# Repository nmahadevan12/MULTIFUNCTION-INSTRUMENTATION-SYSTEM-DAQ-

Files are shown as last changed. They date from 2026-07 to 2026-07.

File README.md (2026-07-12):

# Multifunction Instrumentation System (M.I.S.)

**Developed by Nikhil Mahadevan**

A portable, Raspberry Pi–powered electronic test bench that replaces six lab instruments — ohmmeter, voltmeter, DC reference, square/sine function generator, and frequency meter — with one integrated DAQ platform.




[]()
[]()

---

## Table of Contents

- [Overview](#overview)
- [Instrument Summary](#instrument-summary)
- [System Architecture](#system-architecture)
- [Software Architecture](#software-architecture)
- [Hardware Design](#hardware-design)
  - [Power Supply](#41--12-v-power-supply)
  - [Ohmmeter](#42-ohmmeter)
  - [Voltmeter](#43-voltmeter)
  - [DC Reference](#44-dc-reference)
  - [Square Wave Generator](#45-square-wave-generator)
  - [Sine Wave Measurement](#46-sine-wave-measurement-frequency-meter)
  - [Sine Wave Generator](#47-sine-wave-generator)
- [PCB Design](#pcb-design-kicad)
- [GPIO Pin Map](#gpio-pin-map-system)
- [Getting Started](#getting-started)
- [Demo Videos](#demo-videos)
- [Skills Demonstrated](#skills-demonstrated)

---

## Overview

The Multifunction Instrumentation System integrates oscilloscopes, function generators, and multimeters into a single-board computer platform using the **Raspberry Pi 4** as the central processing unit. Custom analog front-end circuits handle signal conditioning, comparison, and generation; Python firmware orchestrates measurement, waveform output, and a responsive menu-driven UI from a single application.

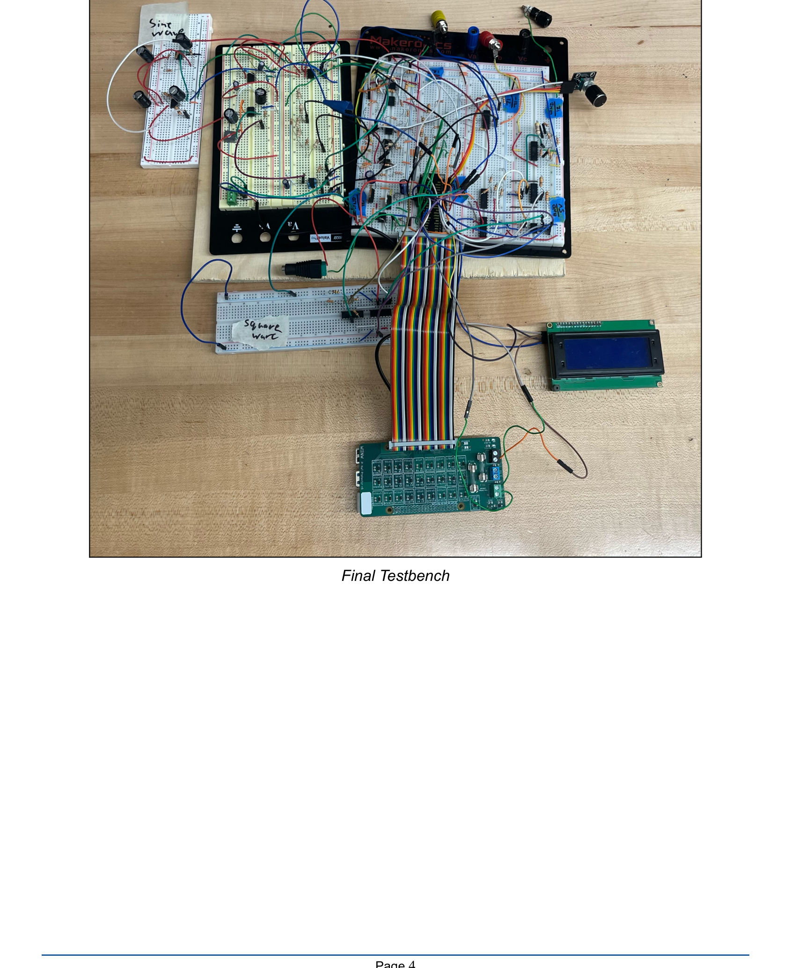
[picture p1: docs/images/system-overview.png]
Final test bench assembly


> [!TIP]
> **Documentation convention:** Images show only schematics, photos, and oscilloscope captures. All objectives, theory, and figure captions are written as markdown text below each image.

<details open>
<summary><strong>At a Glance</strong></summary>

| | |
|---|---|
| **Controller** | Raspberry Pi 4 (sole processor — no external MCU) |
| **Interface** | 20×4 I²C LCD + KY-040 rotary encoder with pushbutton |
| **Analog front-end** | TL084/TL081 op-amps, LM339 comparators, MCP4131/MCP4231 digipots |
| **Power** | 24 V DC input → ±12 V virtual-ground split-rail supply |
| **Firmware** | ~970 lines of Python — SAR measurement, hardware PWM, pigpio edge detection |
| **PCB** | 4-layer KiCad hierarchical design with Gerber manufacturing files |

</details>

<details>
<summary><strong>Project Objectives</strong></summary>

1. **Instrument design**
   - Ohmmeter (500 Ω – 10 kΩ)
   - Voltmeter (−5 V to +5 V)
   - DC reference (−5 V to +5 V)
   - Sine wave frequency measurement (1 – 10 kHz)
   - Function generator — square wave (100 Hz – 10 kHz, ±10 V) and sine wave (1 – 10 kHz, 0 – 10 V pk)

2. **System integration**
   - ±12 V power supply from 24 V input
   - Software-driven successive-approximation measurement (digipot + comparator)
   - Rotary-encoder UI on 20×4 LCD

3. **PCB layout**
   - Full KiCad schematic and 4-layer board design sized to the Raspberry Pi footprint

</details>

<details>
<summary><strong>Design Constraints</strong></summary>

| Category | Constraint |
|---|---|
| **Software** | All logic in Python; pigpio daemon for timing-critical PWM and edge detection |
| **Controller** | Raspberry Pi 4 only — no external microcontrollers |
| **Digipots** | Maximum of 4 digital potentiometers (MCP4131 ×3, MCP4231 ×1 dual-channel) |
| **Power** | All analog power derived from 24 V DC (LCD powered separately); Pi via USB-C |
| **Mechanical** | Pi Hat required — all GPIO routed through hat connector |

</details>

---

## Instrument Summary

| Instrument | Range | Accuracy | Update Rate |
|:---|:---|:---|:---|
| 🔵 **Ohmmeter** | 500 Ω – 10 kΩ | ±10% | 500 ms |
| 🟢 **Voltmeter** | −5 V to +5 V | ±0.2 V | 500 ms |
| 🟡 **DC Reference** | −5.00 V to +4.80 V (32 steps) | ±0.2 V | On demand |
| 🟠 **Square Wave** | 100 Hz – 10 kHz, ±10 V pk | ±1 V amplitude | Real-time PWM |
| 🟣 **Sine Wave** | 1 – 10 kHz, 0 – 10 V pk | ±0.2 V amplitude | Real-time audio |
| 🔴 **Frequency Meter** | 1 – 10 kHz | ±1% | 500 ms |

---

## System Architecture

```mermaid
flowchart LR
    subgraph UI["🖥️ User Interface"]
        LCD["20×4 I²C LCD"]
        ENC["Rotary Encoder"]
    end

    subgraph SW["🐍 Python Firmware"]
        MENU["Menu State Machine"]
        SAR["SAR Engine"]
        PWM["Hardware PWM"]
        FREQ["Edge Detection"]
    end

    subgraph HW["⚡ Analog Front-End"]
        PS["±12V Supply"]
        MEAS["Ohm / Volt"]
        GEN["Wave Gen"]
        DCREF["DC Ref"]
    end

    ENC --> MENU --> LCD
    MENU --> SAR & PWM & FREQ
    SAR & PWM & FREQ --> HW
    PS --> HW
```

---

## Software Architecture

Software is the core of the system — it links the user interface to hardware modules, converts raw comparator signals into resistance/voltage values, controls waveform timing, and keeps the LCD updated.

<details open>
<summary><strong>Platform & Libraries</strong></summary>

| Layer | Technology |
|---|---|
| OS | Raspberry Pi OS |
| Execution | Standalone Python script (`Main Code/16.py`) |
| GPIO / PWM | `RPi.GPIO`, `pigpio` (hardware PWM + µs edge timestamps) |
| SPI | `spidev` — MCP4131 / MCP4231 digital potentiometers |
| I²C | `smbus2`, `RPLCD` — 20×4 character LCD |
| UI input | `gpiozero` — rotary encoder + button callbacks |

</details>

<details>
<summary><strong>Navigation & Main Loop</strong></summary>

The interface is a **stack-based menu tree** with automatic hardware cleanup on back-navigation. Measurement modes sample every **500 ms**; the LCD refreshes on a 50 ms display flag with thread-safe writes.

To ensure a highly responsive user interface, the **500 ms** hardware measurement routines run asynchronously or utilize non-blocking sleep intervals. This prevents the synchronous 8-bit SPI SAR sweeps from blocking encoder interrupt callbacks or delaying the **50 ms** LCD UI refresh cycle.

```
while True:
    if display_needs_update → render_interface()
    if measurement_mode     → sample hardware every 500 ms
    if leaving_mode         → cleanup GPIO / stop waveforms
    sleep(0.05)
```

</details>

<details>
<summary><strong>Per-Instrument Firmware</strong></summary>

| Instrument | Key Implementation |
|---|---|
| **Square wave** | Hardware PWM GPIO 12 + MCP4231 amplitude/offset over SPI |
| **Sine wave** | Pi audio jack + `speaker-test`; MCP4131 amplitude (CS GPIO 17) |
| **Ohmmeter** | 8-iter SAR on MCP4131; `R = R_known × (step / (128 − step))` |
| **Voltmeter** | SAR on GPIO 6; lookup table + linear interpolation |
| **DC Reference** | 5-bit R-2R on GPIO 14, 15, 18, 23, 24 |
| **Frequency** | pigpio edge callbacks GPIO 25; 100-period buffer, >2σ outlier reject |

</details>

> [!IMPORTANT]
> All waveform and DC outputs **automatically disable** when leaving a menu — a built-in safety interlock.

---

## Hardware Design

### 4.1 ±12 V Power Supply

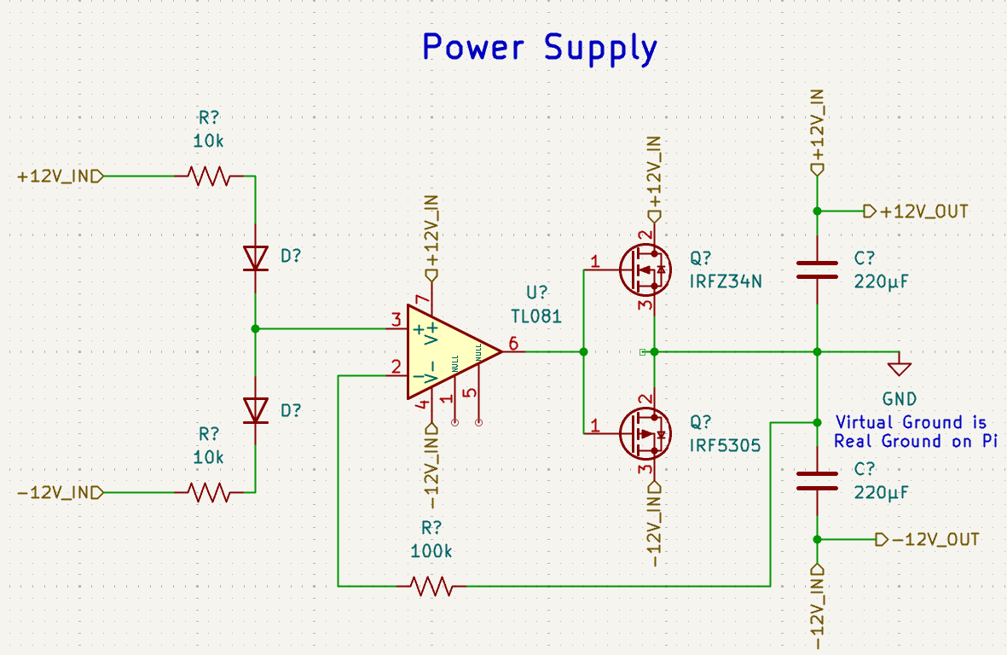
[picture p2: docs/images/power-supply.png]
Power supply schematic


*Figure 4.1.1: Power Supply Schematic*

<details open>
<summary><strong>Power Supply — Theory & Integration</strong></summary>

**Objective:** Split a +24 V DC input into symmetric +12 V and −12 V rails to power op-amps throughout the system. Rails must remain stable under varying load.

**Theory of Operation:** Virtual ground from a 24 V source. TL081 unity-gain follower at the 12 V midpoint drives IRFZ34N + IRF5305 push-pull stage. Virtual ground tied to Pi GND → +12 V above, −12 V below. The virtual ground node acts as the absolute **0 V** reference point for all analog measurements. To prevent heavy analog return currents from injecting noise into the digital plane, the Raspberry Pi GND is tied to this virtual ground at a **single star-ground point** right at the power entry terminal.

1. **Voltage reference:** Matched 10 kΩ divider + Zener clamping → 12 V at TL081 pin 3
2. **Unity-gain buffering:** 100 kΩ feedback drives MOSFET gates
3. **Push-pull output:** NMOS sources / PMOS sinks load current at virtual ground
4. **Output stabilization:** 220 µF bulk caps per rail

**Physical Integration:** Breadboard; ±12 V via terminal blocks. **GPIO:** None — analog only.

</details>

<details>
<summary><strong>Power Supply — Test Results</strong></summary>

| Test Condition | Negative Rail | Positive Rail | Current |
|---|---|---|---|
| Both loads connected | −12.04 V | +12.05 V | ~12 mA each |
| No load | −12.05 V | +12.06 V | — |
| Negative load only | 12.05 V | — | 12.10 mA |
| Positive load only | — | 12.06 V | 12.08 mA |

</details>

> [!WARNING]
> MOSFETs run warm under heavy load. Observe electrolytic capacitor polarity on each rail.

---

### 4.2 Ohmmeter

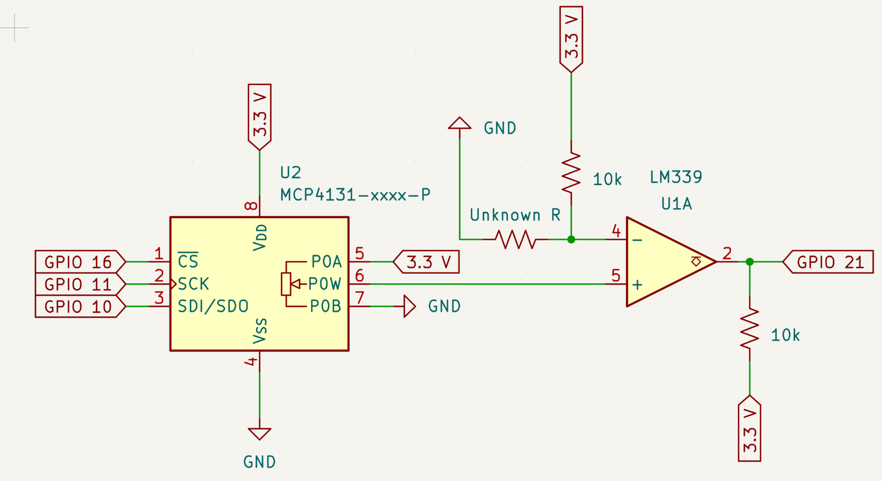
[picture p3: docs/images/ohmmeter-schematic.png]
Ohmmeter schematic


*Figure 4.2.1: Ohmmeter Schematic*

<details open>
<summary><strong>Ohmmeter — Theory & GPIO</strong></summary>

**Objective:** High-accuracy auto-ranging digital ohmmeter for **500 Ω to 10 kΩ**.

**Theory of Operation:** Voltage divider with unknown resistor vs. **7-bit MCP4131** programmable reference. Successive approximation across 128 wiper steps; LM339 comparator on GPIO 21. LCD updates every 500 ms with ±10% tolerance. A fixed series current-limiting resistor (**R_limit = 1 kΩ**) is placed in series with the unknown device under test (DUT). This keeps the maximum current through the MCP4131 wiper well below its absolute maximum rating of **2.5 mA** even when measuring low resistances down to **500 Ω**.

| Signal | GPIO | Component Pin |
|---|---|---|
| Chip Select (CS) | 8 | MCP4131 Pin 1 |
| SPI Clock (SCK) | 11 | MCP4131 Pin 2 |
| SPI Data (SDI/SDO) | 10 | MCP4131 Pin 3 |
| Comparator Output | 21 | LM339 Output |

> [!NOTE]
> **SAR performance (8-bit search):** Each iteration writes one MCP4131 wiper step over SPI (1 MHz, 2-byte frame ≈ 16 µs), waits **5 ms** for the divider/comparator to settle (`sleep(0.005)`), then reads GPIO 21. Eight bisection steps → **≈40 ms** per resistance reading, well under the **500 ms** LCD refresh cadence. Quantization is set by the **128-step** digipot (7-bit effective range); resistance resolution is non-linear with step (`R = R_known × step / (128 − step)`) and tightest near the matched mid-scale point. Because the voltage-divider topology yields a non-linear resolution across the 128-step digipot, measurement precision peaks when the unknown resistance closely matches the internal reference (**R_known**). Near the outer bounds (**500 Ω** and **10 kΩ**), step-size quantization broadens, which accounts for the specified worst-case **±10%** tolerance.

</details>

---

### 4.3 Voltmeter

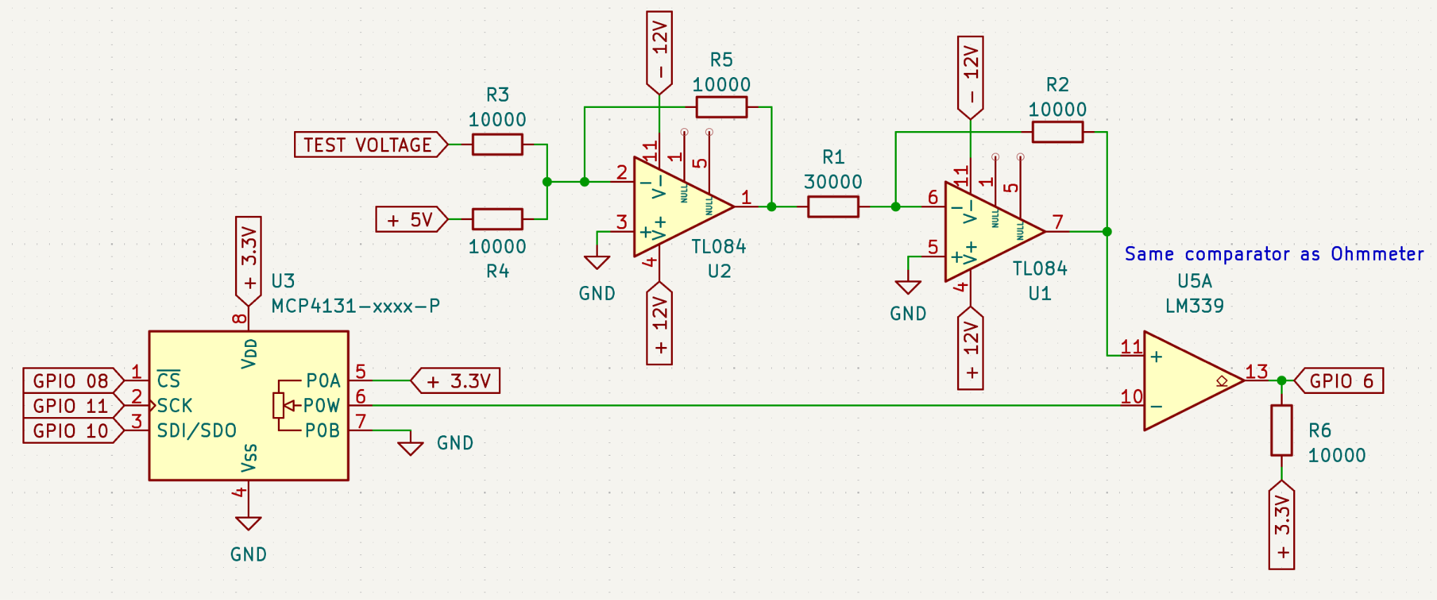
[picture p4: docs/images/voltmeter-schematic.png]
Voltmeter schematic


*Figure 4.3.1: Voltmeter Schematic*

<details open>
<summary><strong>Voltmeter — Theory & GPIO</strong></summary>

**Objective:** Measure **−5 V to +5 V** at ±0.2 V accuracy. Dual-source: external input or internal DC reference verification.

**Theory of Operation:**

1. **U2 — Inverting summing amp:** Maps −5 V to +5 V → 0 V to −10 V
2. **U1 — Inverting amp:** Gain −1/3 → **0 to +3.3 V**
3. **U3 — MCP4131:** 128-step programmable reference via SPI
4. **U5A — LM339:** Comparator with 10 kΩ pull-up
5. **GPIO 6:** Binary search until reference matches test voltage

| Signal | GPIO | Component Pin |
|---|---|---|
| Chip Select (CS) | 8 | MCP4131 Pin 1 |
| SPI Clock (SCK) | 11 | MCP4131 Pin 2 |
| SPI Data (SDI/SDO) | 10 | MCP4131 Pin 3 |
| Comparator Output | 6 | LM339 Pin 13 |

> [!NOTE]
> **SAR performance (8-bit search):** Same 8-iteration binary search as the ohmmeter — one SPI wiper write + **5 ms** settle per step → **≈40 ms** total sweep, safely below the **500 ms** display refresh rate. The ±10 V input span maps to 128 comparator steps, giving a theoretical **≈78 mV/step** (`10 V / 128 ≈ 78 mV`); linear interpolation between calibrated lookup points improves display accuracy to ±0.2 V.

**Calibration & Testing:** Verified against reference multimeter across full range. SAR converges in 8 iterations. ±0.2 V accuracy; best precision near 0 V.

</details>

---

### 4.4 DC Reference

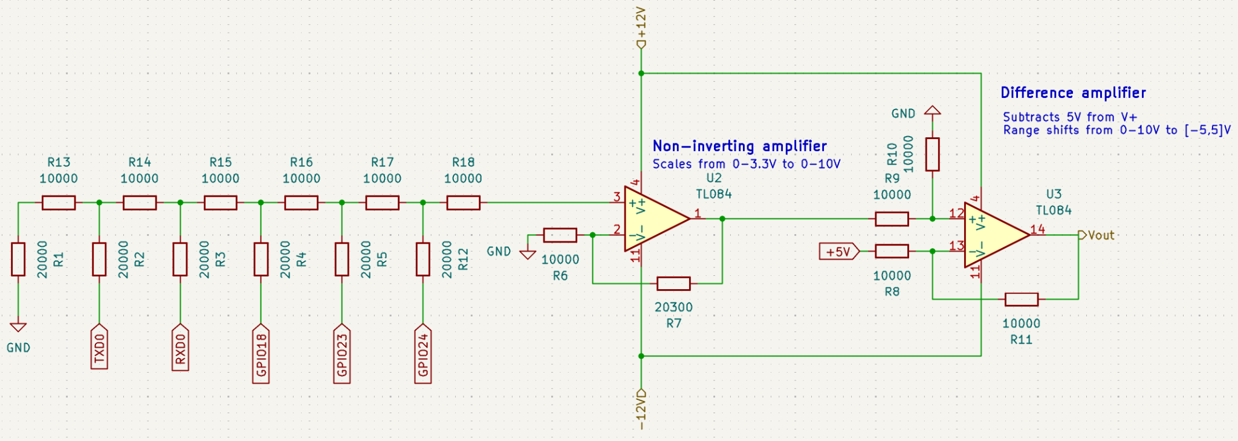
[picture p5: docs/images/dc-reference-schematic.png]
DC reference schematic


*Figure 4.4.1: DC Ref Schematic*

<details open>
<summary><strong>DC Reference — Theory</strong></summary>

**Objective:** Programmable DC output **−5 V to +5 V** in 0.625 V steps (32 levels).

1. **R-2R DAC:** GPIO 14, 15, 18, 23, 24 → binary-weighted divider
2. **U2 — Non-inverting amp:** Gain ≈ 3.03 scales 0–3.3 V → 0–10 V
3. **U3 — Difference amp:** +5 V bias → **−5 V to +5 V** output

**Calibration & Testing:** Output verified across all 32 steps with a reference multimeter. Monotonic response confirmed from −5 V to +5 V.

</details>

<details>
<summary><strong>Previous Design Iteration (Figure 4.4.2)</strong></summary>

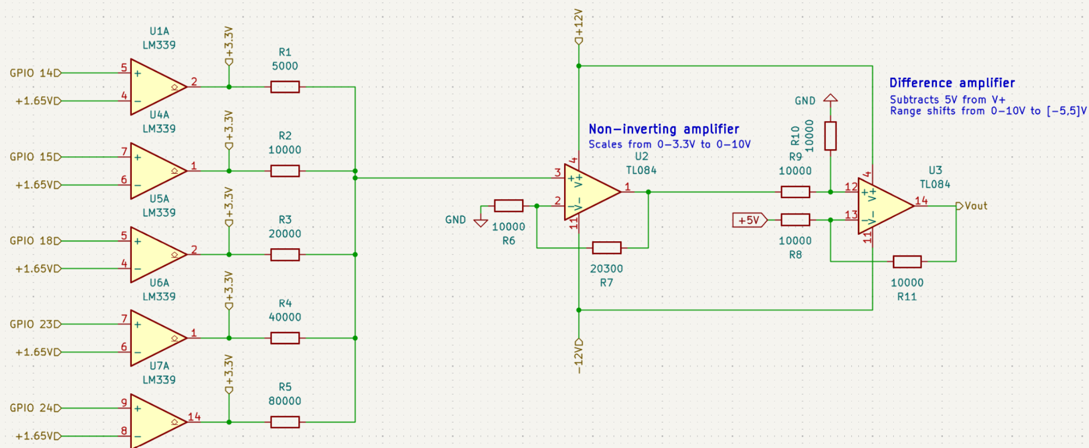
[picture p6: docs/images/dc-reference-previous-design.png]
Previous DC reference schematic


*Figure 4.4.2: Previous DC Ref Schematic*

Original binary-weighted DAC with per-GPIO comparator buffers suffered **cross-loading**. R-2R ladder maintains uniform 2R impedance regardless of bit pattern. The R-2R ladder ensures the digital pins always see a constant output impedance of **R** (or **2R** depending on the node), preventing the voltage sag and non-monotonicity caused by varying pin source impedances in the previous binary-weighted layout.

</details>

---

### 4.5 Square Wave Generator

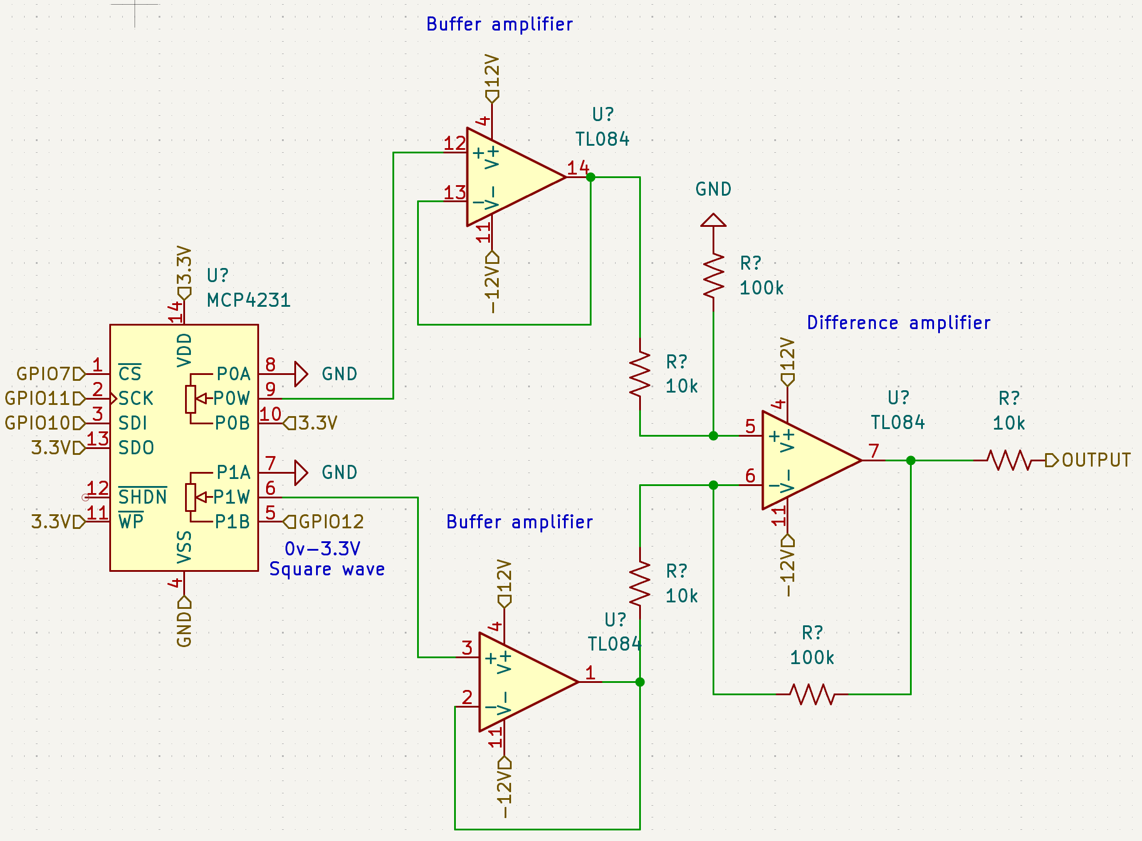
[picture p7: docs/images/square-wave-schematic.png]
Square wave generator schematic


*Figure 4.5.1: Square Wave Schematic*

<details open>
<summary><strong>Square Wave — Theory & GPIO</strong></summary>

**Objective:** Variable square wave centered at **0 V**, up to **±10 V**, high-Z output for oscilloscope use.

**Theory:** Pi hardware PWM GPIO 12 → MCP4231 amplitude + offset → difference amplifier (gain 10) → ±10 V. The hardware PWM output from GPIO 12 passes through a dedicated **RC low-pass filter** stage to smooth high-frequency switching transients and stabilize the signal envelope before amplitude scaling, maintaining waveform integrity across the **100 Hz to 10 kHz** band.

| Signal | GPIO | MCP4231 Pin |
|---|---|---|
| PWM Output | 12 | Ch1 Pin B |
| Chip Select | 7 | Pin 1 |
| SPI Clock | 11 | Pin 3 |
| SPI Data In | 10 | Pin 4 |

**Calibration & Testing:**

- **Figure 4.5.2 — ±7 V initial:** −7.24 V min / +5.95 V max (miscentered)
- **Figure 4.5.3 — ±5 V @ 100 Hz:** Offset ratio **0.45** → ±3% centering
- **Figure 4.5.4 — ±10 V @ 100 Hz:** Full swing confirmed

</details>

<details>
<summary><strong>Oscilloscope Captures</strong></summary>

Oscilloscope — square wave at 1 kHz during initial characterization

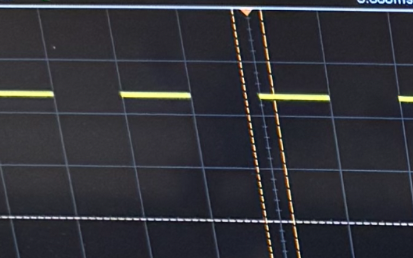
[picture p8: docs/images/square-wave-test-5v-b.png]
Oscilloscope — ±5 V square wave at 100 Hz, final result


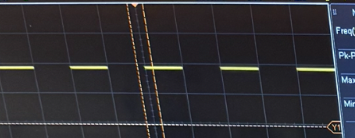
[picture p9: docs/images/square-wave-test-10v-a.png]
Oscilloscope — ±10 V square wave at 100 Hz, final result


</details>

---

### 4.6 Sine Wave Measurement (Frequency Meter)

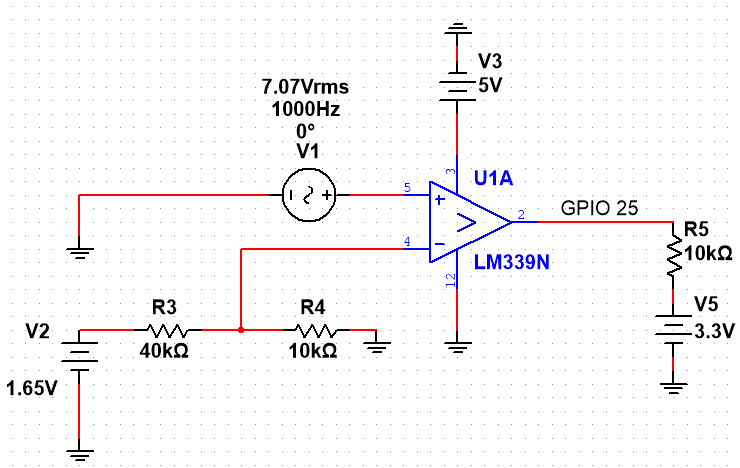
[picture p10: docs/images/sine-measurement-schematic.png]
Sine wave measurement schematic


*Figure 4.6.1: Sine Wave Measurement Schematic*

<details open>
<summary><strong>Frequency Meter — Theory & GPIO</strong></summary>

**Objective:** Measure **0 V to +10 V** sine input frequency from **1 kHz to 10 kHz**.

**Theory:** LM339 threshold at **+1.65 V** → digital edges on GPIO 25 → **f = 1/T**. 100-period rolling buffer with >2σ outlier rejection.

**pigpio edge architecture:** On standard Linux (non-real-time), Python thread scheduling would jitter any bit-banged timing. The `pigpio` daemon sidesteps this by sampling GPIO transitions with **hardware-level DMA**, stamping each rising edge with a **microsecond-accurate tick** (`pigpio.tickDiff`) in a background buffer. The Python callback only appends period samples; `compute_frequency()` runs on the 500 ms UI loop, decoupling the timing-critical edge capture from GIL contention and kernel scheduling delay.

| Signal | GPIO | Component Pin |
|---|---|---|
| Comparator Output | 25 | LM339 Output |
| External Input | — | LM339 Non-Inverting Input |
| Reference (+1.65 V) | — | LM339 Inverting Input |

**Calibration & Testing:** ±2% tolerance across 1 – 10 kHz.

</details>

---

### 4.7 Sine Wave Generator

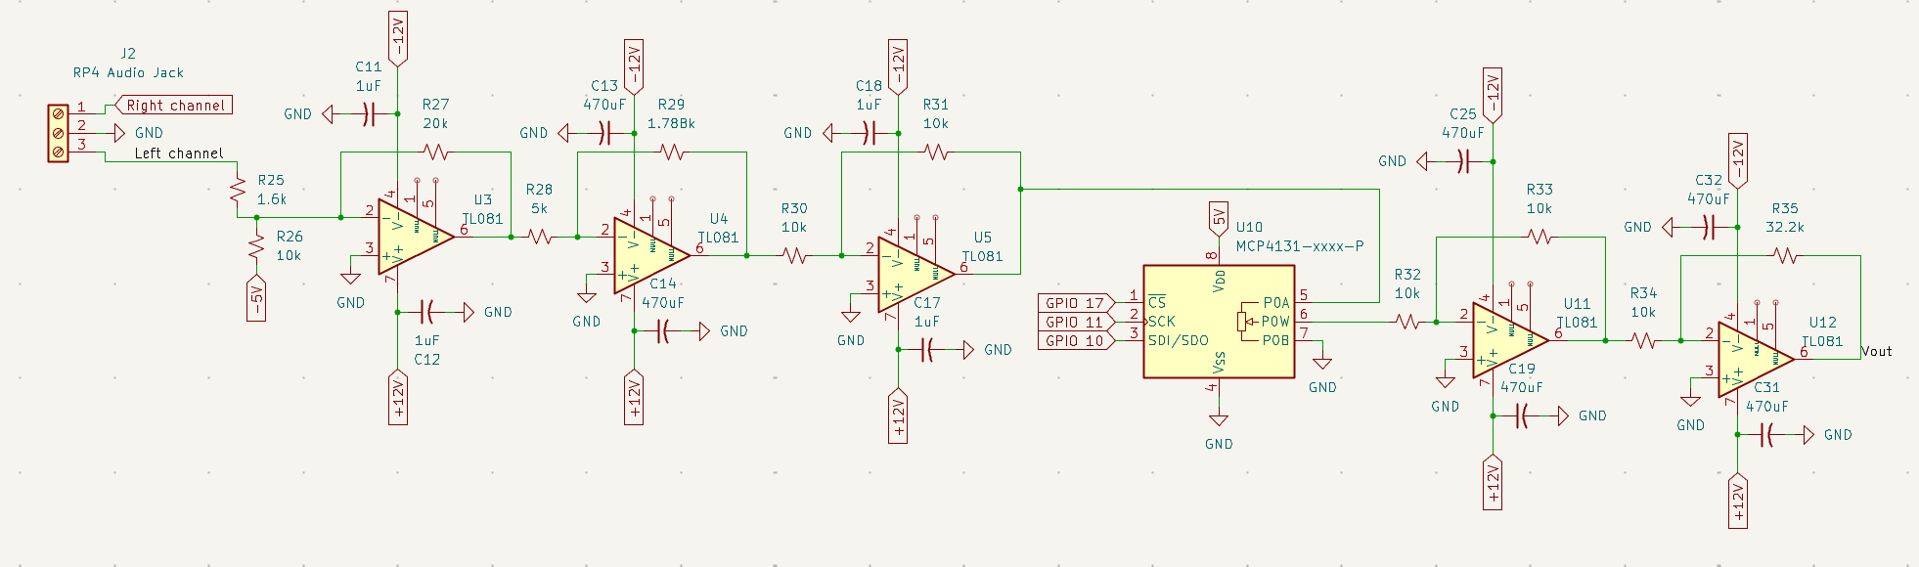
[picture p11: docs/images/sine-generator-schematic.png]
Sine wave generator schematic


<details open>
<summary><strong>Sine Wave Generator — Theory & GPIO</strong></summary>

**Objective:** **0 – 10 V peak** sine wave from **1 kHz to 10 kHz**.

1. **U3 — TL081 buffer:** Pi audio jack + −5 V DC offset
2. **U4 & U5 — Scaling:** Normalize to 0–3.3 V. Because the Raspberry Pi audio jack outputs a line-level AC signal (≈1 V pk-pk), **U4** is configured as a non-inverting amplifier with a hardware gain of **A_v ≈ 3.3** to scale the raw audio voltage up to the required **3.3 V** internal logic dynamic range before attenuation.
3. **U10 — MCP4131:** Digital attenuation via SPI
4. **U11 & U12 — Output:** Reconstruct to 0–10 V

| Signal | GPIO | MCP4131 Pin |
|---|---|---|
| Chip Select | 17 | Pin 1 |
| SPI Clock | 11 | Pin 2 |
| SPI Data | 10 | Pin 3 |

</details>

---

## PCB Design (KiCad)

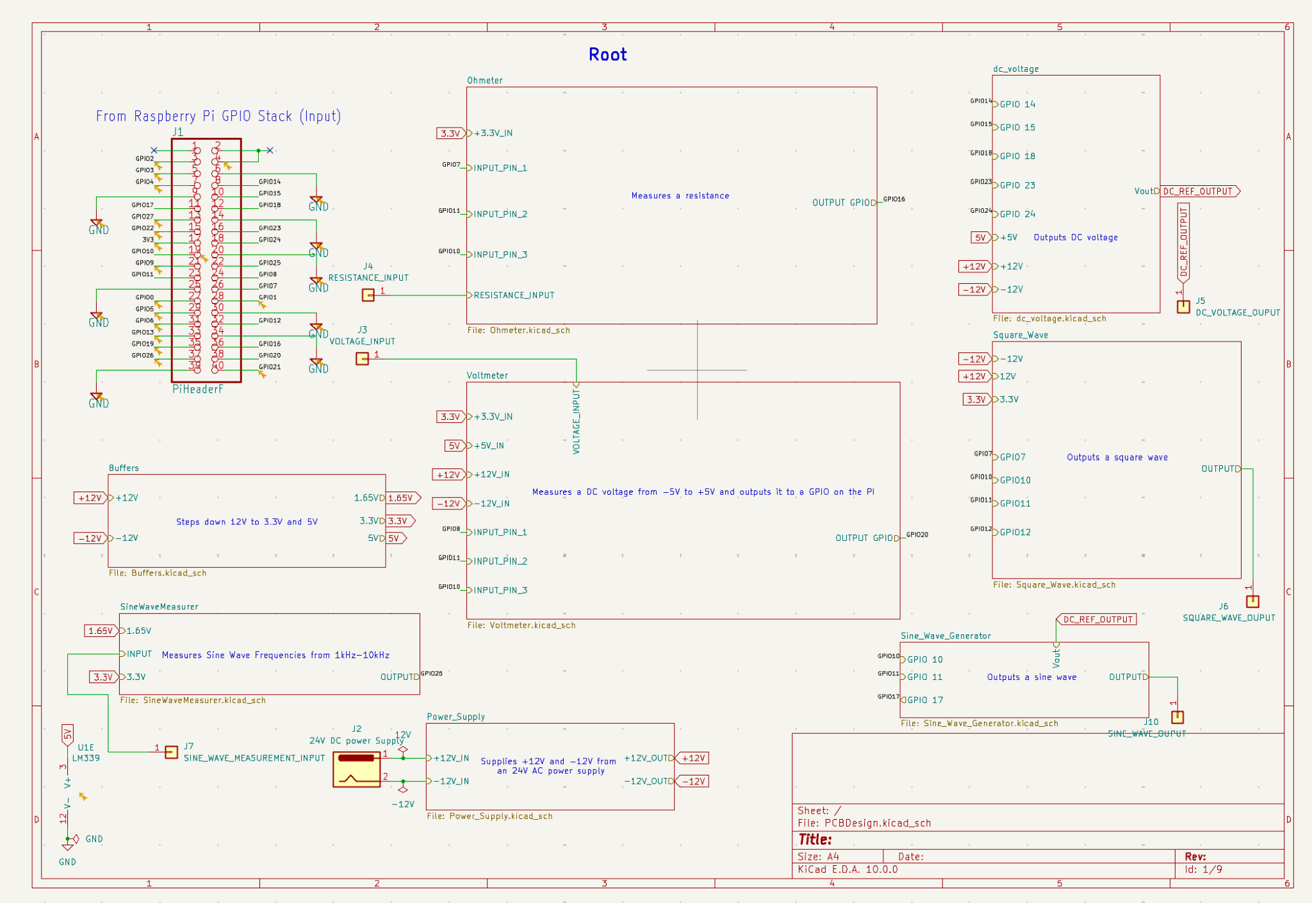
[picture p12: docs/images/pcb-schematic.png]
Hierarchical PCB schematic


*Figure 5.2.1: Final PCB Schematic*

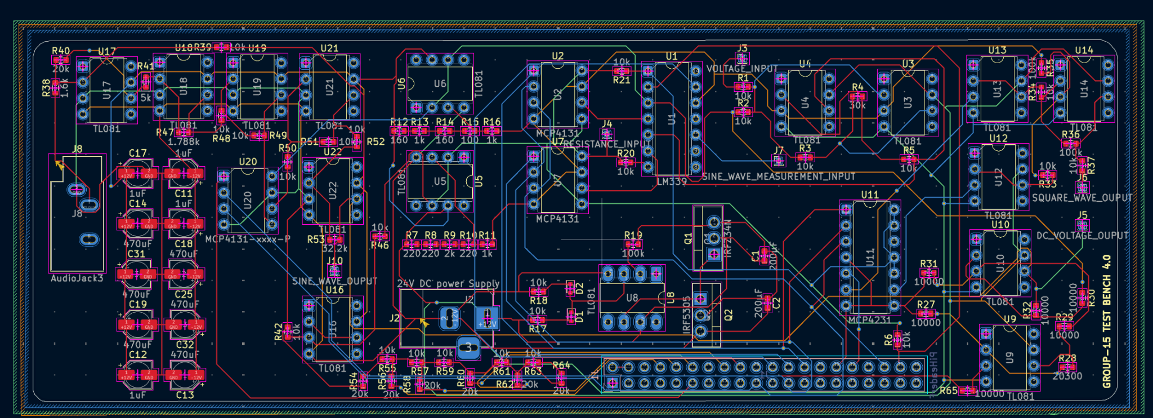
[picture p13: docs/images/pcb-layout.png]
PCB board layout


*Figure 5.2.2: Final PCB Board*

<details>
<summary><strong>PCB Design Details</strong></summary>

- **CAD tool:** KiCad — free, full-featured
- **Schematic:** Hierarchical sub-sheets per instrument; max 4 layers
- **Layout:** Subsystem grouping, through-hole + SMD passives, 45° routing
- **Manufacturing:** DRC-checked Gerbers in `PCBDesign/` (designed, not manufactured)

</details>

---

## GPIO Pin Map (System)

<details open>
<summary><strong>Full GPIO Map — click to expand</strong></summary>

| GPIO | Signal | Component | Description |
|:---:|:---|:---|:---|
| 2, 3 | SDA, SCL | LCD | I²C character display |
| 6 | Input | LM339 | Voltmeter comparator |
| 7 | SPI CS | MCP4231 | Square wave digipot |
| 8 | SPI CS | MCP4131 | Ohmmeter / voltmeter digipot |
| 10 | SPI MOSI | MCP4131/4231 | SPI data |
| 11 | SPI SCLK | MCP4131/4231 | SPI clock |
| 12 | HW PWM | — | Square wave output |
| 13, 19 | Input | KY-040 | Rotary encoder A/B |
| 14, 15, 18, 23, 24 | Output | R-2R ladder | DC reference (5-bit) |
| 17 | SPI CS | MCP4131 | Sine amplitude digipot |
| 21 | Input | LM339 | Ohmmeter comparator |
| 25 | Interrupt | LM339 | Frequency measurement |
| 26 | Input | KY-040 | Encoder button (3 s hold = back) |

</details>

---

## Getting Started

> [!NOTE]
> GPIO access requires `sudo`. The `pigpio` daemon must be running for PWM and frequency measurement.

<details open>
<summary><strong>Install & Run</strong></summary>

```bash
sudo apt update && sudo apt install -y python3-pip pigpio python3-pigpio alsa-utils
sudo systemctl enable --now pigpio
pip install -r requirements.txt
sudo python3 "Main Code/16.py"
```

</details>

<details>
<summary><strong>Controls Cheat Sheet</strong></summary>

| Action | Control |
|---|---|
| Scroll | Rotate encoder |
| Select / confirm | Short press |
| Back / cancel | Hold 3 seconds |
| Edit value | Rotate in edit mode, press to confirm |

Power Pi via **USB-C**, analog circuits via **24 V DC**. Wait ~20 s after boot.

</details>

---

## Demo Videos

<details open>
<summary><strong>Watch demos — click any link</strong></summary>

| Feature | Link |
|---|---|
| Power-on & setup | [YouTube](https://youtu.be/CEZYySeiEv4) |
| Menu navigation | [YouTube](https://youtu.be/Nd_8IkFf7bE) |
| Ohmmeter | [YouTube](https://youtu.be/j0UAiwsbkE0) |
| Voltmeter (external) | [YouTube](https://youtube.com/shorts/AqCL2ivuH78) |
| Voltmeter (internal ref) | [YouTube](https://youtube.com/shorts/lTq6MlFrF2s) |
| Square wave | [YouTube](https://youtube.com/shorts/NfCk3m-b2u8) |
| Sine wave | [YouTube](https://youtube.com/shorts/mf1v4rBYL3M) |
| Frequency measurement | [YouTube](https://youtube.com/shorts/Z5qWBG-sBkY) |

</details>

---

## Future Improvements

> [!TIP]
> Planned next steps: 12–16 bit external ADC, manufactured 4-layer PCB with ground planes, BNC/screw-terminal I/O, on-board regulators, active analog shielding.

---

## Skills Demonstrated

<table>
<tr>
<td width="50%">

**Embedded Systems**
- GPIO, hardware PWM, SPI/I²C
- pigpio edge detection
- SAR algorithms
- Thread-safe concurrent access

**Software Engineering**
- State-machine UI
- Stack navigation
- Lookup tables
- ~970 LOC firmware

</td>
<td width="50%">

**Analog Design**
- Op-amp conditioning
- Comparator front-ends
- R-2R DAC
- Virtual-ground power

**PCB / Systems**
- KiCad hierarchical design
- 4-layer layout
- End-to-end HW/SW co-design
- Safety interlocks

</td>
</tr>
</table>

---

<p align="center">
  
</p>

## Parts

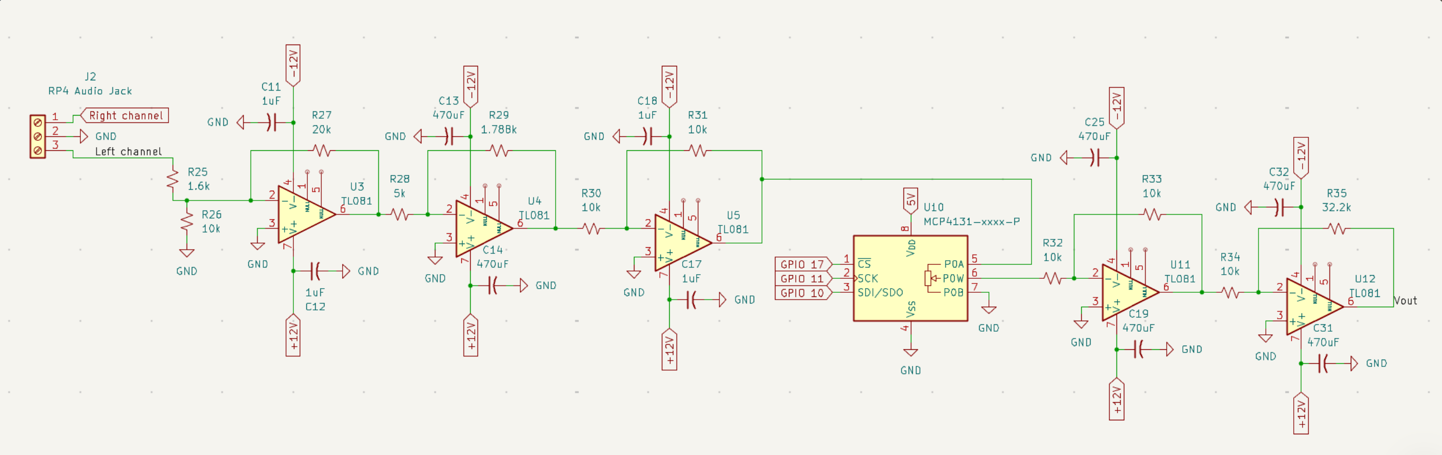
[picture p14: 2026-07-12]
Individual Components/7 - Sine Wave Generator/sin_wave_generator.png

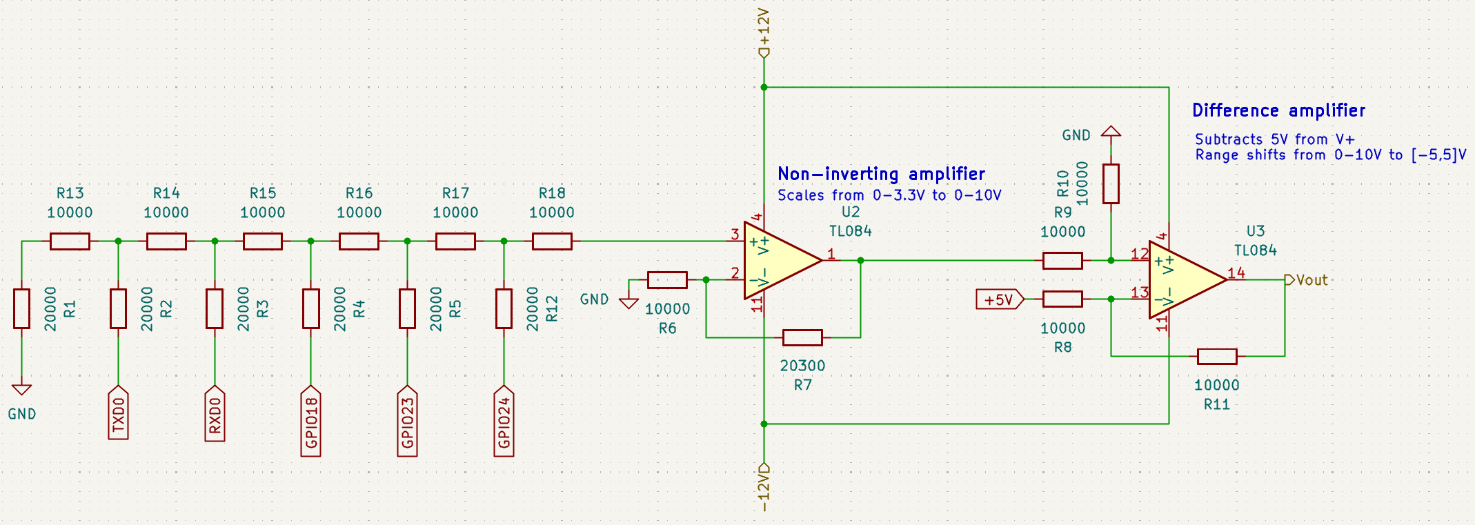
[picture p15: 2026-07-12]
Individual Components/4 - DC Ref/DC_Ref.png

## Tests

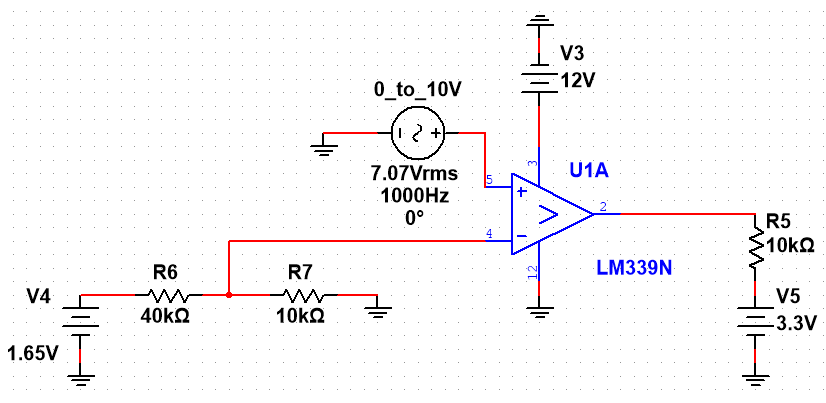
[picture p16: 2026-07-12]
Individual Components/6 - Sine Wave Measurer/Sine Wave Mes.png

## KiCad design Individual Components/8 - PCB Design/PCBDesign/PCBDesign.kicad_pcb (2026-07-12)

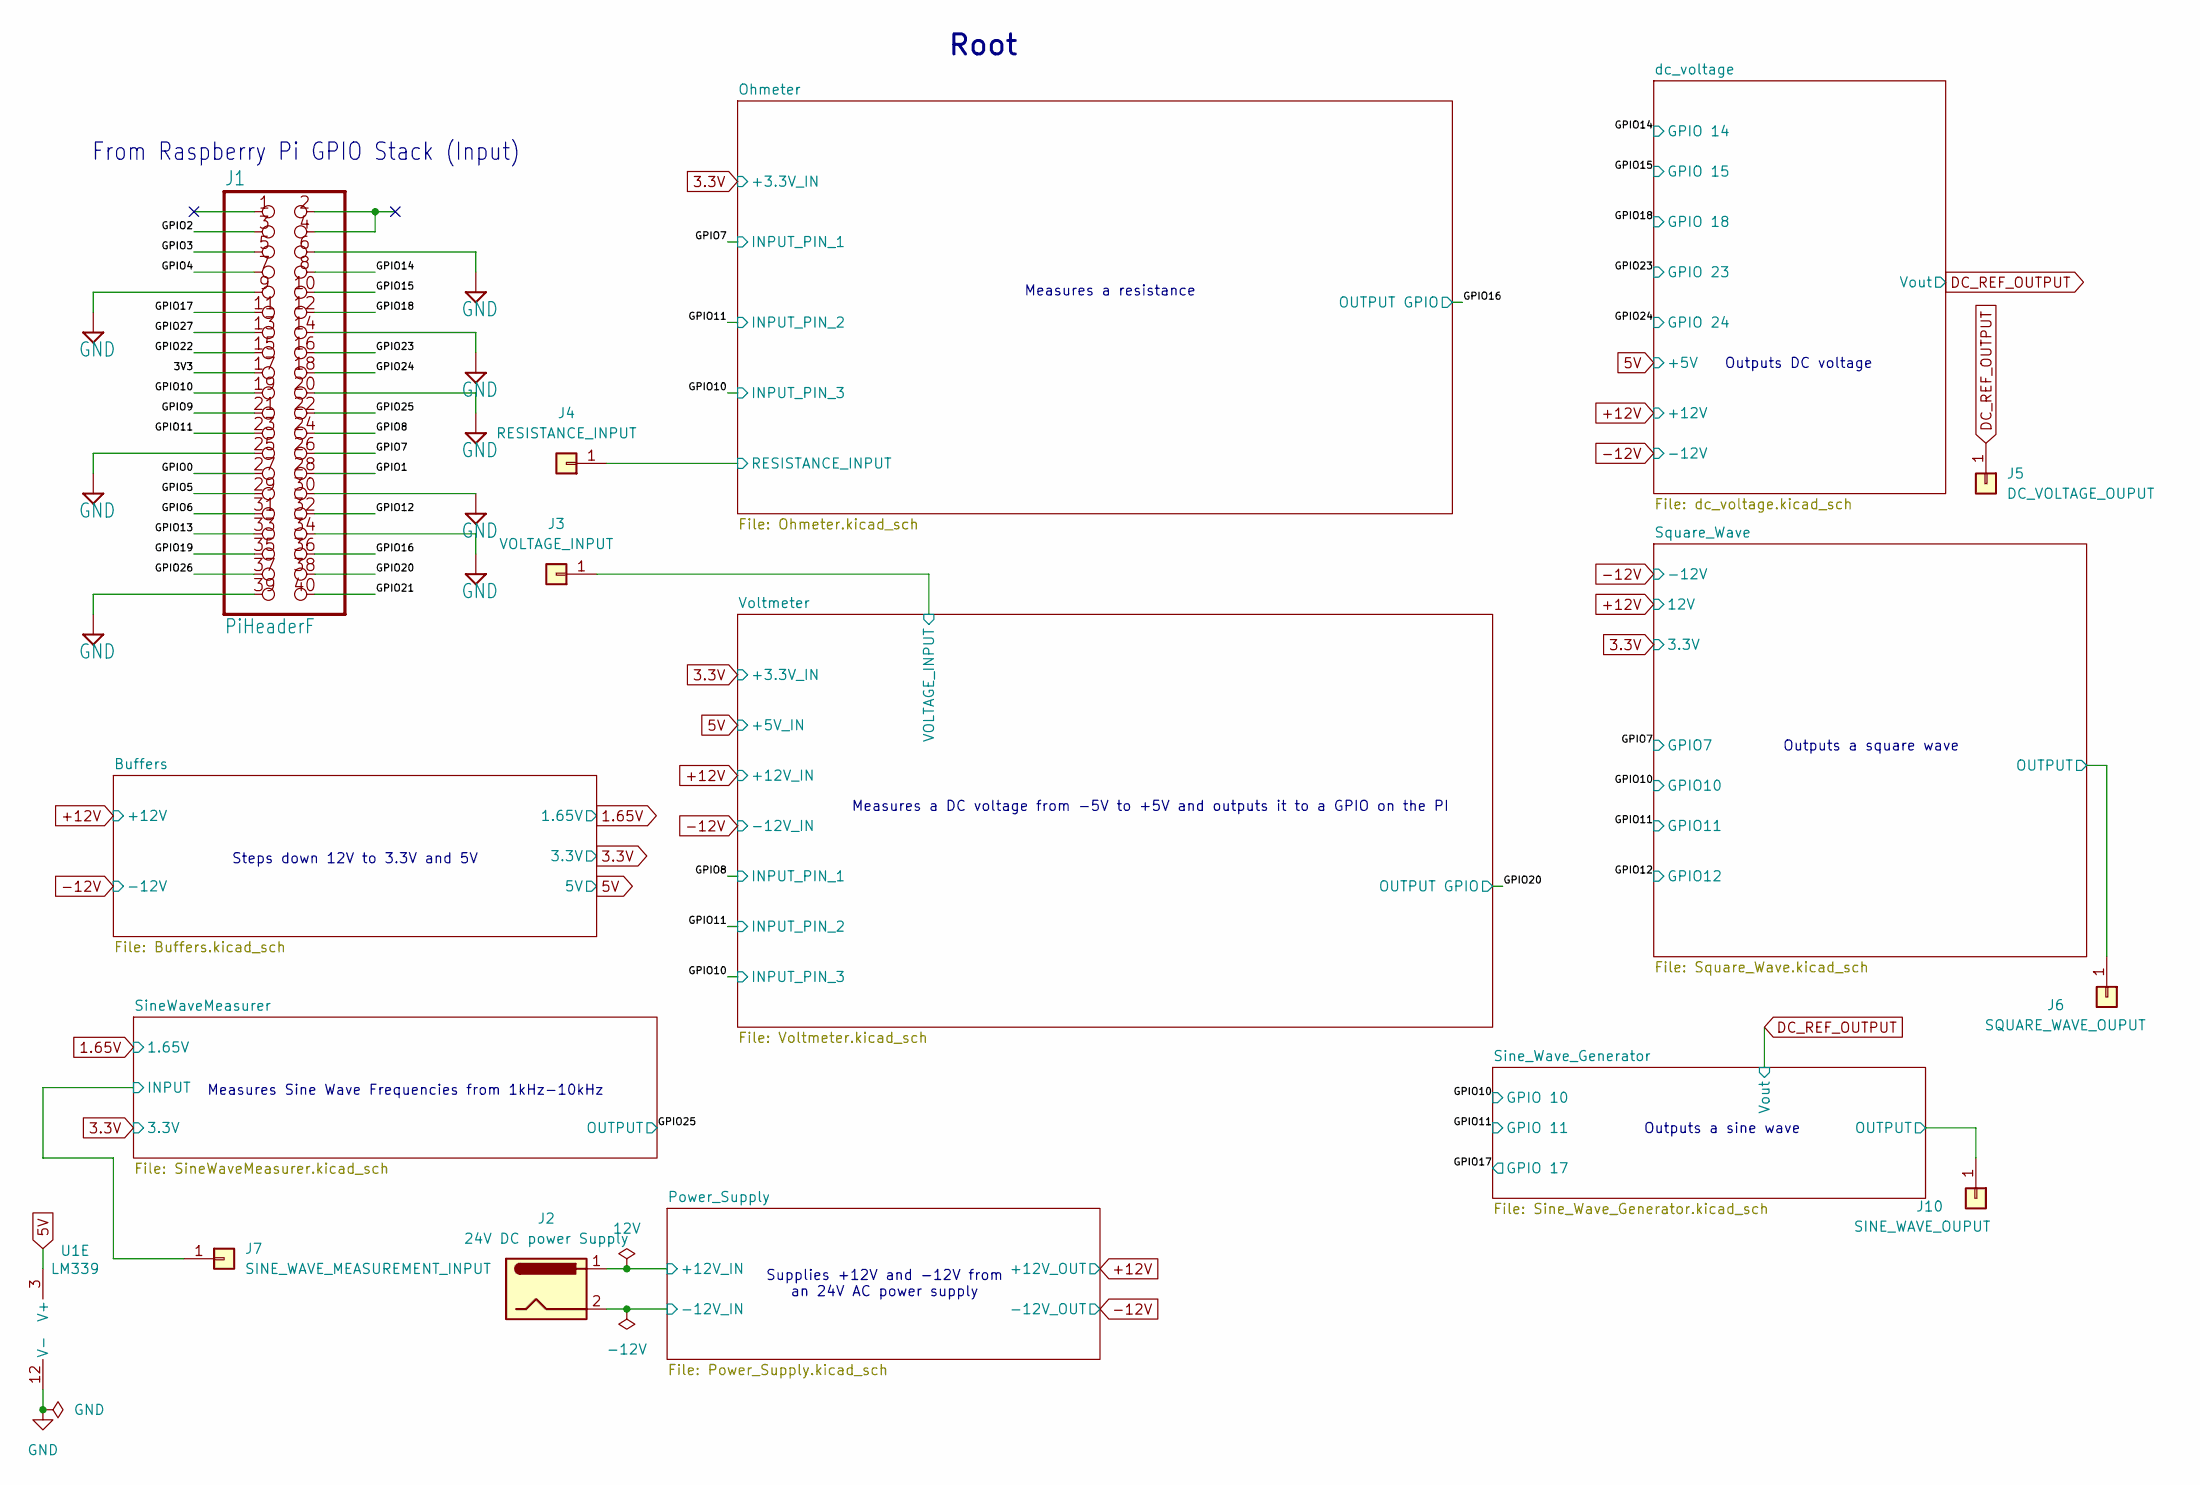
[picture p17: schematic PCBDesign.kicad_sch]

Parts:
J1: PiHeaderF; PinSocket_2x20_P2.54mm_Vertical
J2: 24V DC power Supply; BarrelJack_Horizontal
J3: VOLTAGE_INPUT; PinHeader_1x01_P1.00mm_Vertical
J4: RESISTANCE_INPUT; PinHeader_1x01_P1.00mm_Vertical
J5: DC_VOLTAGE_OUPUT; PinHeader_1x01_P1.00mm_Vertical
J6: SQUARE_WAVE_OUPUT; PinHeader_1x01_P1.00mm_Vertical
J7: SINE_WAVE_MEASUREMENT_INPUT; PinHeader_1x01_P1.00mm_Vertical
J10: SINE_WAVE_OUPUT; PinHeader_1x01_P1.00mm_Vertical
U1: LM339; DIP-14_W7.62mm

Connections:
3.3V: J4.1 (Pin_1_1); also elsewhere on the board
5V: U1.3 (V+); also elsewhere on the board
+12V: J2.1; also elsewhere on the board
-12V: J2.2; also elsewhere on the board
/3V3: J1.17
/GPIO0: J1.27
/GPIO1: J1.28
/GPIO2: J1.3
/GPIO3: J1.5
/GPIO4: J1.7
/GPIO5: J1.29
/GPIO6: J1.31
/GPIO7: J1.26; also elsewhere on the board
/GPIO8: J1.24; also elsewhere on the board
/GPIO9: J1.21
/GPIO10: J1.19; also elsewhere on the board
/GPIO11: J1.23; also elsewhere on the board
/GPIO12: J1.32; also elsewhere on the board
/GPIO13: J1.33
/GPIO14: J1.8; also elsewhere on the board
/GPIO15: J1.10; also elsewhere on the board
/GPIO16: J1.36; also elsewhere on the board
/GPIO17: J1.11; also elsewhere on the board
/GPIO18: J1.12; also elsewhere on the board
/GPIO19: J1.35
/GPIO20: J1.38; also elsewhere on the board
/GPIO21: J1.40
/GPIO22: J1.15
/GPIO23: J1.16; also elsewhere on the board
/GPIO24: J1.18; also elsewhere on the board
/GPIO25: J1.22; also elsewhere on the board
/GPIO26: J1.37
/GPIO27: J1.13
/SineWaveMeasurer/INPUT: J7.1 (Pin_1_1); also elsewhere on the board
/Square_Wave/OUTPUT: J6.1 (Pin_1_1); also elsewhere on the board
/Voltmeter/VOLTAGE_INPUT: J3.1 (Pin_1_1); also elsewhere on the board
DC_REF_OUTPUT: J5.1 (Pin_1_1), J10.1 (Pin_1_1); also elsewhere on the board
GND: J1.6, J1.9, J1.14, J1.20, J1.25, J1.30, J1.34, J1.39, U1.12 (V-); also elsewhere on the board

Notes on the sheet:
Measures a DC voltage from -5V to +5V and outputs it to a GPIO on the PI
Measures Sine Wave Frequencies from 1kHz-10kHz
Supplies +12V and -12V from an 24V AC power supply
Outputs a sine wave
From Raspberry Pi GPIO Stack (Input)
Outputs a square wave
Outputs DC voltage
Steps down 12V to 3.3V and 5V
Measures a resistance
Root

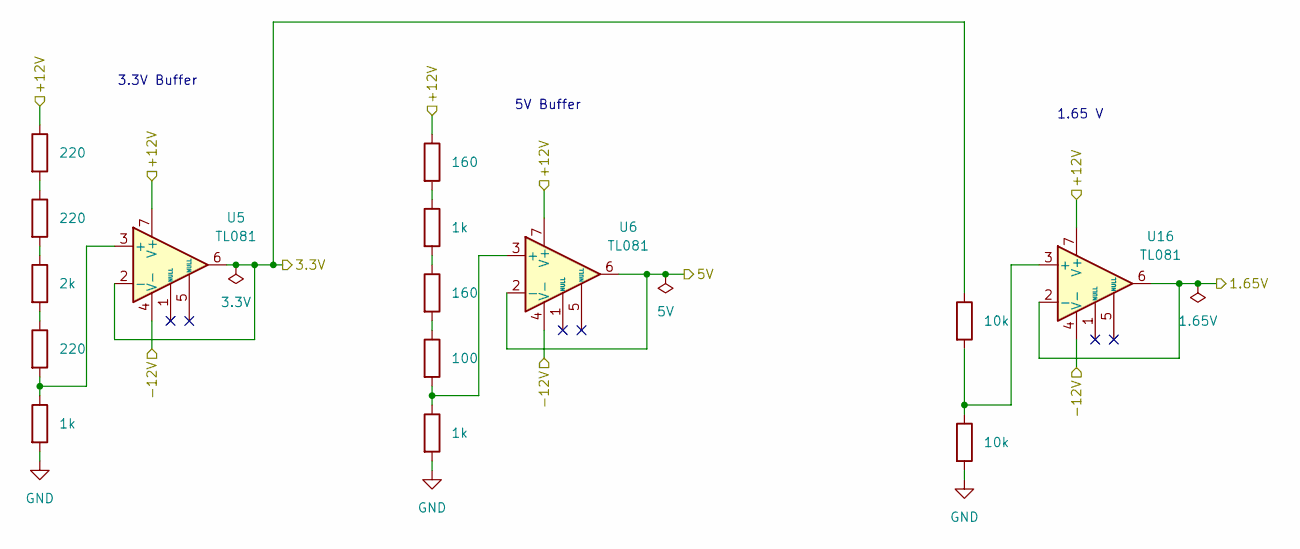
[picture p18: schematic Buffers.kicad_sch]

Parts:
R7, R8, R10: 220; R_0603_1608Metric
R9: 2k; R_0603_1608Metric
R11, R13, R16: 1k; R_0603_1608Metric
R12, R14: 160; R_0603_1608Metric
R15: 100; R_0603_1608Metric
R42, R46: 10k; R_0603_1608Metric
U5, U6, U16: TL081; DIP-8_W7.62mm

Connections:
1.65V: U16.2 (-), U16.6
3.3V: R46.1, U5.2 (-), U5.6; also elsewhere on the board
5V: U6.2 (-), U6.6; also elsewhere on the board
+12V: R7.1, R12.1, U5.7 (V+), U6.7 (V+), U16.7 (V+); also elsewhere on the board
-12V: U5.4 (V-), U6.4 (V-), U16.4 (V-); also elsewhere on the board
GND: R11.2, R16.2, R42.2; also elsewhere on the board
unnamed: R7.2, R8.1
unnamed: R8.2, R9.1
unnamed: R9.2, R10.1
unnamed: R12.2, R13.1
unnamed: R13.2, R14.1
unnamed: R14.2, R15.1
unnamed: R10.2, R11.1, U5.3 (+)
unnamed: R15.2, R16.1, U6.3 (+)
unnamed: R42.1, R46.2, U16.3 (+)

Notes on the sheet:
3.3V Buffer
5V Buffer
1.65 V

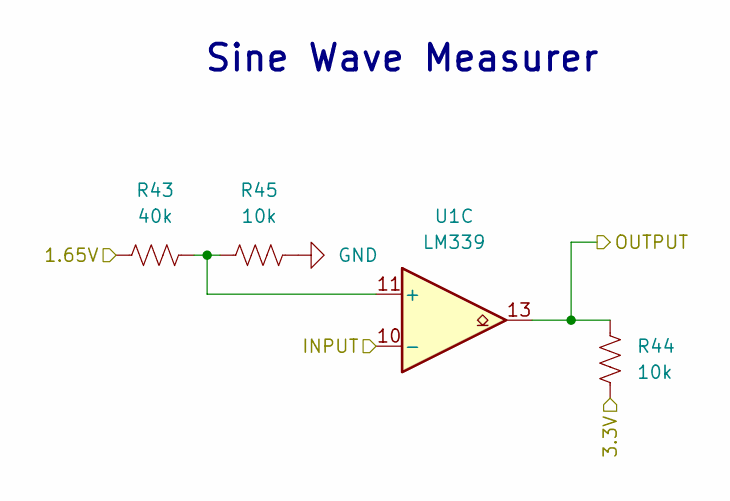
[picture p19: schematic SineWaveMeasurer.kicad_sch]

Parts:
R43: 40k
R44, R45: 10k
U1: LM339; DIP-14_W7.62mm

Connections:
/GPIO25: R44.1, U1.13; also elsewhere on the board
/SineWaveMeasurer/INPUT: U1.10 (-); also elsewhere on the board
unnamed: R43.2, R45.1, U1.11 (+)

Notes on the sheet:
Sine Wave Measurer

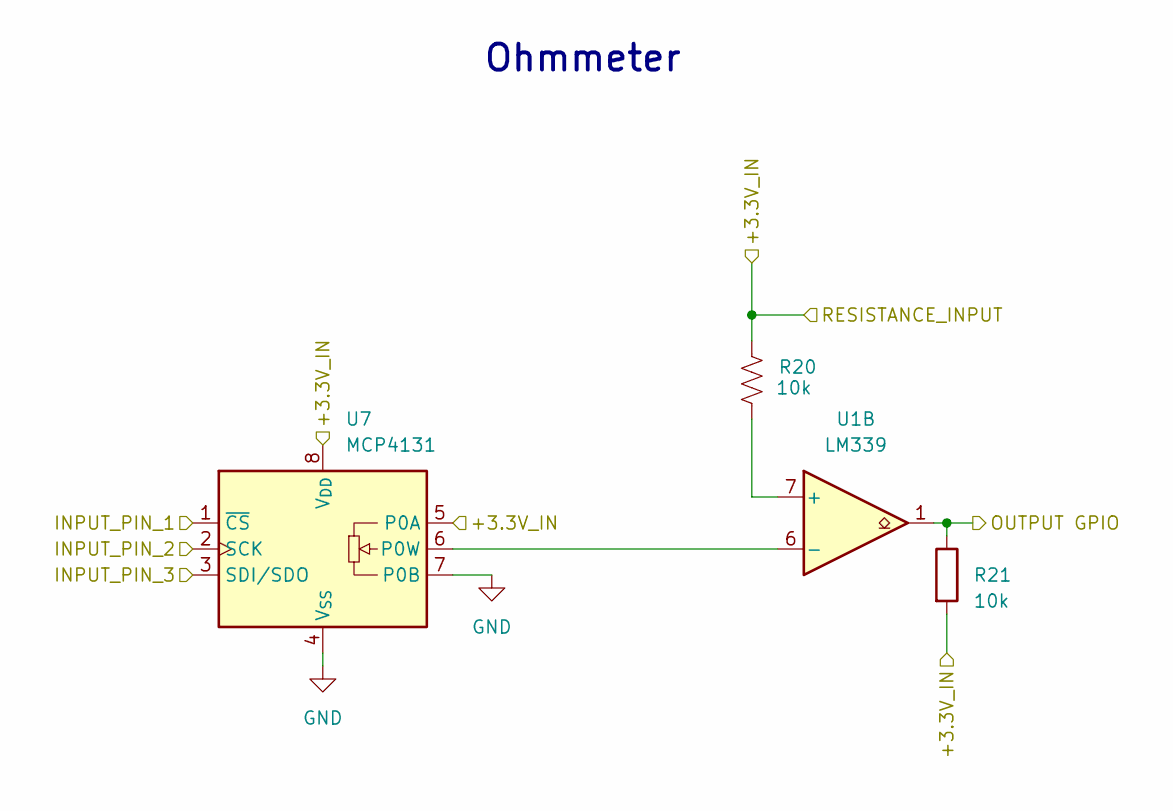
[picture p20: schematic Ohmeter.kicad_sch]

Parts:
R20, R21: 10k; R_0603_1608Metric
U1: LM339; DIP-14_W7.62mm
U7: MCP4131; DIP-8_W7.62mm

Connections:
3.3V: R20.1, R21.2, U7.5 (P0A), U7.8 (V_{DD}); also elsewhere on the board
/GPIO7: U7.1 (~CS); also elsewhere on the board
/GPIO10: U7.3 (SDI/SDO); also elsewhere on the board
/GPIO11: U7.2 (SCK); also elsewhere on the board
/GPIO16: R21.1, U1.1; also elsewhere on the board
GND: U7.4 (V_{SS}), U7.7 (P0B); also elsewhere on the board
unnamed: R20.2, U1.7 (+)
unnamed: U1.6 (-), U7.6 (P0W)

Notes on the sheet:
Ohmmeter

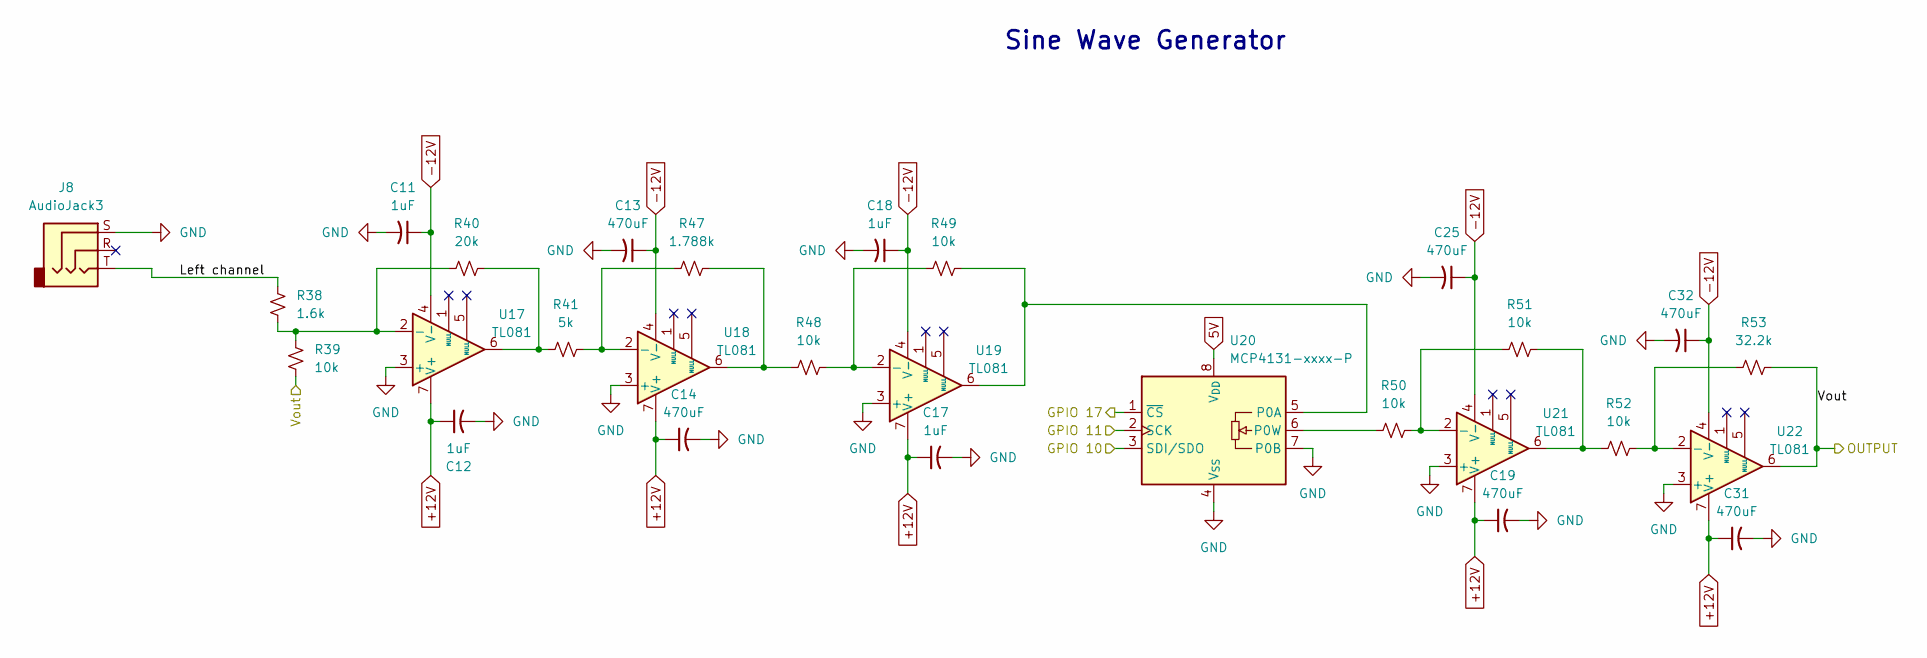
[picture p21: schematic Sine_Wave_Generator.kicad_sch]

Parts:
C11, C12, C17, C18: 1uF; CP_Elec_4x3
C13, C14, C19, C25, C31, C32: 470uF; CP_Elec_4x3
J8: AudioJack3; Jack_3.5mm_CUI_SJ1-3533NG_Horizontal
R38: 1.6k; R_0603_1608Metric
R39, R48, R49, R50, R51, R52: 10k; R_0603_1608Metric
R40: 20k; R_0603_1608Metric
R41: 5k; R_0603_1608Metric
R47: 1.788k; R_0603_1608Metric
R53: 32.2k; R_0603_1608Metric
U17, U18, U19, U21, U22: TL081; DIP-8_W7.62mm
U20: MCP4131-xxxx-P; DIP-8_W7.62mm

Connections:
5V: U20.8 (V_{DD}); also elsewhere on the board
+12V: C12.1, C14.1, C17.1, C19.1, C31.1, U17.7 (V+), U18.7 (V+), U19.7 (V+), U21.7 (V+), U22.7 (V+); also elsewhere on the board
-12V: C11.1, C13.1, C18.1, C25.1, C32.1, U17.4 (V-), U18.4 (V-), U19.4 (V-), U21.4 (V-), U22.4 (V-); also elsewhere on the board
/GPIO10: U20.3 (SDI/SDO); also elsewhere on the board
/GPIO11: U20.2 (SCK); also elsewhere on the board
/GPIO17: U20.1 (~CS); also elsewhere on the board
/Sine_Wave_Generator/Left channel: J8.T, R38.1
DC_REF_OUTPUT: R39.2, R53.2, U22.6; also elsewhere on the board
GND: C11.2, C12.2, C13.2, C14.2, C17.2, C18.2, C19.2, C25.2, C31.2, C32.2, J8.S, U17.3 (+), U18.3 (+), U19.3 (+), U20.4 (V_{SS}), U20.7 (P0B), U21.3 (+), U22.3 (+); also elsewhere on the board
unnamed: R40.2, R41.1, U17.6
unnamed: R47.2, R48.1, U18.6
unnamed: R51.2, R52.1, U21.6
unnamed: R38.2, R39.1, R40.1, U17.2 (-)
unnamed: R41.2, R47.1, U18.2 (-)
unnamed: R48.2, R49.1, U19.2 (-)
unnamed: R49.2, U19.6, U20.5 (P0A)
unnamed: R50.1, U20.6 (P0W)
unnamed: R50.2, R51.1, U21.2 (-)
unnamed: R52.2, R53.1, U22.2 (-)

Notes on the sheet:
Sine Wave Generator

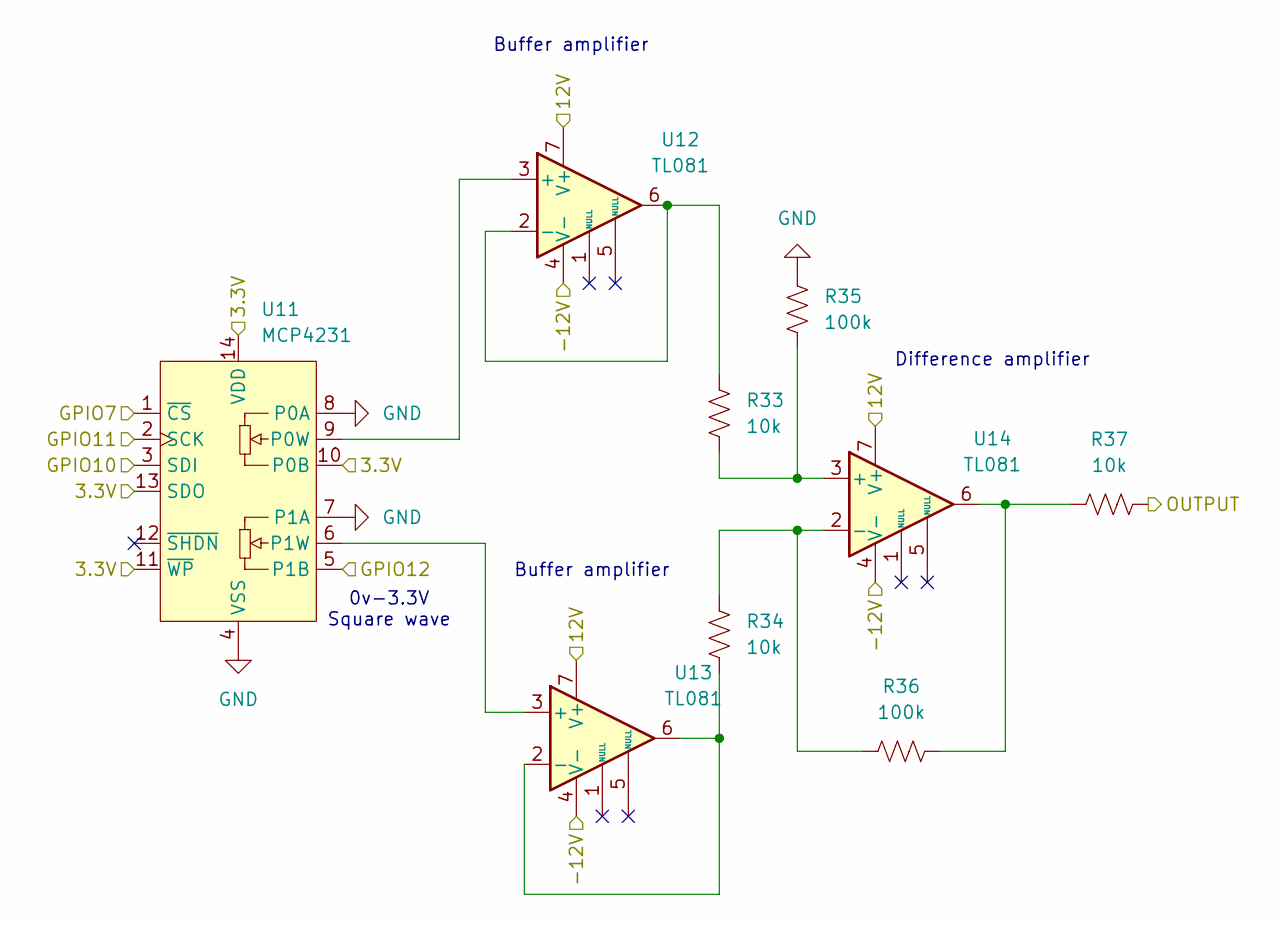
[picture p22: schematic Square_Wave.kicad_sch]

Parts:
R33, R34, R37: 10k; R_0603_1608Metric
R35, R36: 100k; R_0603_1608Metric
U11: MCP4231; DIP-14_W7.62mm
U12, U13, U14: TL081; DIP-8_W7.62mm

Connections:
3.3V: U11.10 (P0B), U11.11 (~WP), U11.13 (SDO), U11.14 (VDD); also elsewhere on the board
+12V: U12.7 (V+), U13.7 (V+), U14.7 (V+); also elsewhere on the board
-12V: U12.4 (V-), U13.4 (V-), U14.4 (V-); also elsewhere on the board
/GPIO7: U11.1 (~CS); also elsewhere on the board
/GPIO10: U11.3 (SDI); also elsewhere on the board
/GPIO11: U11.2 (SCK); also elsewhere on the board
/GPIO12: U11.5 (P1B); also elsewhere on the board
/Square_Wave/OUTPUT: R37.2; also elsewhere on the board
GND: R35.1, U11.4 (VSS), U11.7 (P1A), U11.8 (P0A); also elsewhere on the board
unnamed: R36.2, R37.1, U14.6
unnamed: U11.9 (P0W), U12.3 (+)
unnamed: U11.6 (P1W), U13.3 (+)
unnamed: R33.1, U12.2 (-), U12.6
unnamed: R34.2, U13.2 (-), U13.6
unnamed: R33.2, R35.2, U14.3 (+)
unnamed: R34.1, R36.1, U14.2 (-)

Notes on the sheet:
0v-3.3V Square wave
Buffer amplifier
Difference amplifier

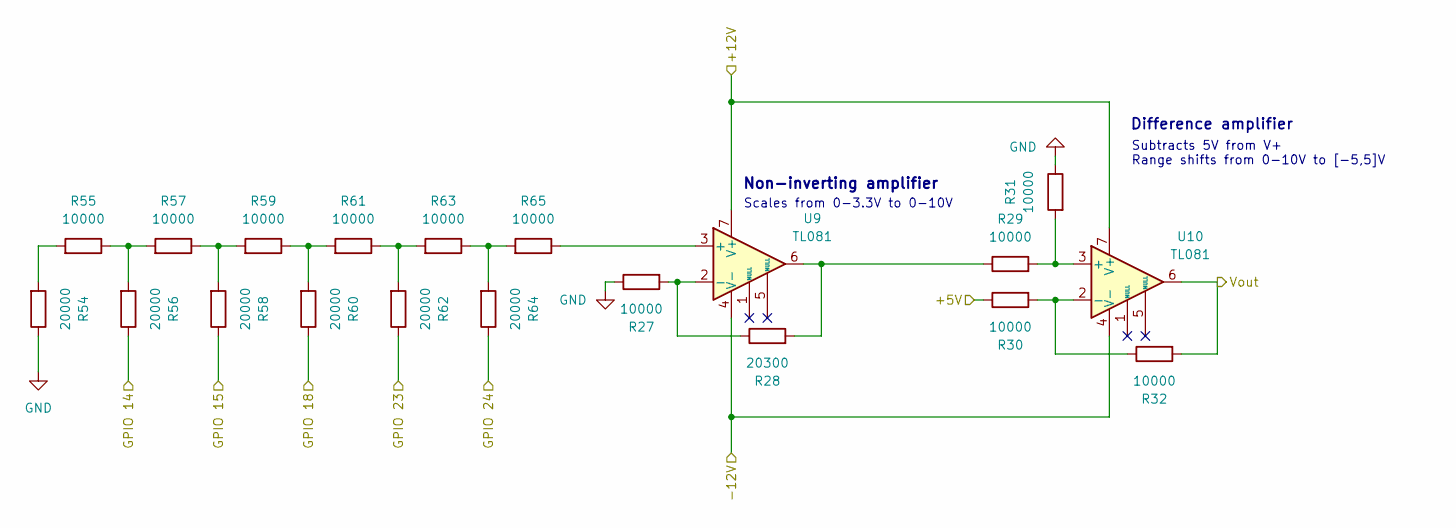
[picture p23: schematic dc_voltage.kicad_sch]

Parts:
R27, R29, R30, R31, R32, R55, R57, R59, R61, R63, R65: 10000; R_0603_1608Metric
R28: 20300; R_0603_1608Metric
R54, R56, R58, R60, R62, R64: 20000; R_0603_1608Metric
U9, U10: TL081; DIP-8_W7.62mm

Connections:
5V: R30.1; also elsewhere on the board
+12V: U9.7 (V+), U10.7 (V+); also elsewhere on the board
-12V: U9.4 (V-), U10.4 (V-); also elsewhere on the board
/GPIO14: R56.1; also elsewhere on the board
/GPIO15: R58.1; also elsewhere on the board
/GPIO18: R60.1; also elsewhere on the board
/GPIO23: R62.1; also elsewhere on the board
/GPIO24: R64.1; also elsewhere on the board
DC_REF_OUTPUT: R32.2, U10.6; also elsewhere on the board
GND: R27.1, R31.1, R54.1; also elsewhere on the board
unnamed: R28.2, R29.1, U9.6
unnamed: R54.2, R55.2
unnamed: R55.1, R56.2, R57.2
unnamed: R57.1, R58.2, R59.2
unnamed: R59.1, R60.2, R61.2
unnamed: R61.1, R62.2, R63.2
unnamed: R63.1, R64.2, R65.2
unnamed: R65.1, U9.3 (+)
unnamed: R27.2, R28.1, U9.2 (-)
unnamed: R29.2, R31.2, U10.3 (+)
unnamed: R30.2, R32.1, U10.2 (-)

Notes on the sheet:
Difference amplifier
Scales from 0-3.3V to 0-10V
Non-inverting amplifier
Subtracts 5V from V+ Range shifts from 0-10V to [-5,5]V

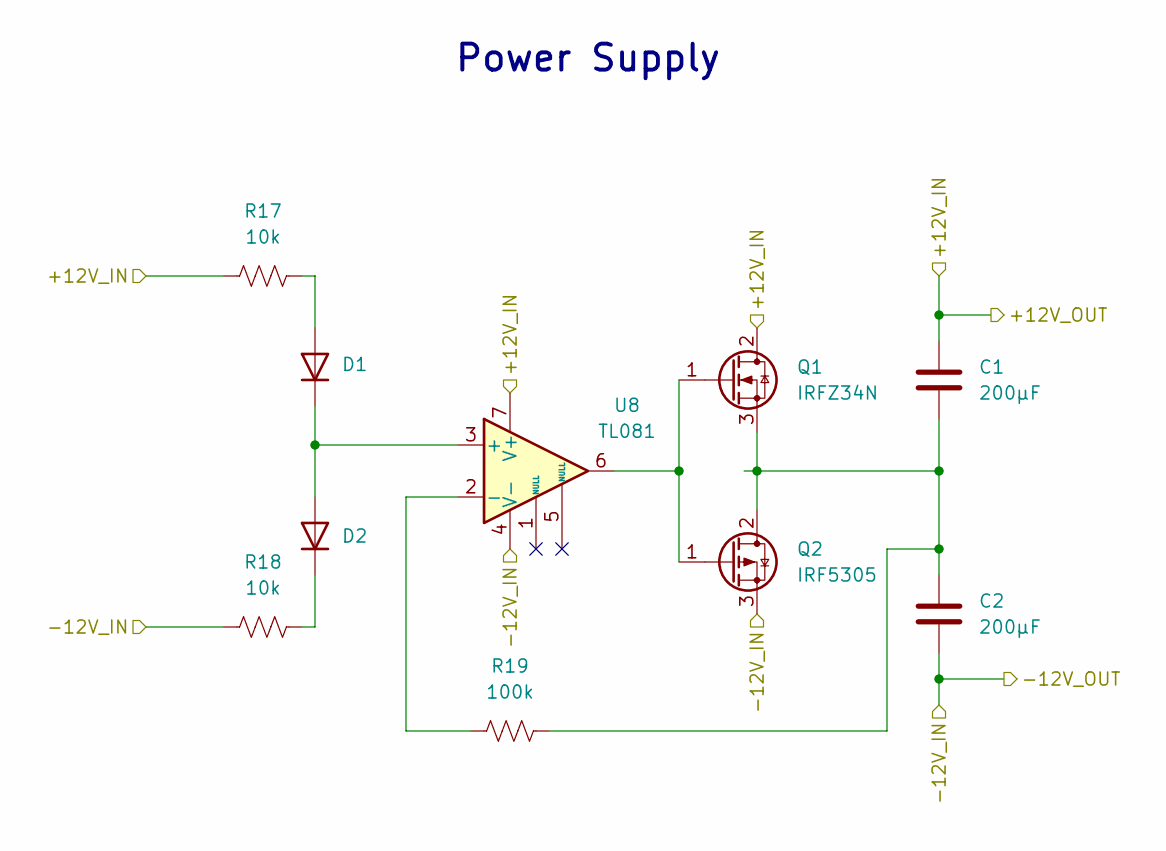
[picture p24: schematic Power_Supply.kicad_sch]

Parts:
C1, C2: 200µF; C_0603_1608Metric
D1, D2: 1N4148WT; D_SOD-523
Q1: IRFZ34N; TO-220-3_Vertical
Q2: IRF5305; TO-220-3_Vertical
R17, R18: 10k; R_0603_1608Metric
R19: 100k; R_0603_1608Metric
U8: TL081; DIP-8_W7.62mm_LongPads

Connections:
+12V: C1.1, Q1.2 (D), R17.2, U8.7 (V+); also elsewhere on the board
-12V: C2.2, Q2.3 (S), R18.2, U8.4 (V-); also elsewhere on the board
unnamed: D1.2 (A), R17.1
unnamed: D1.1 (K), D2.2 (A), U8.3 (+)
unnamed: D2.1 (K), R18.1
unnamed: Q1.1 (G), Q2.1 (G), U8.6
unnamed: C1.2, C2.1, Q1.3 (S), Q2.2 (D), R19.2
unnamed: R19.1, U8.2 (-)

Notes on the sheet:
Power Supply

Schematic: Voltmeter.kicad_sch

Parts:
R1, R2, R3, R5, R6: 10k; R_0603_1608Metric
R4: 30k; R_0603_1608Metric
U1: LM339; DIP-14_W7.62mm
U2: MCP4131; DIP-8_W7.62mm
U3, U4: TL081; DIP-8_W7.62mm

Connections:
3.3V: R6.2, U2.5 (P0A), U2.8 (V_{DD}); also elsewhere on the board
5V: R2.1; also elsewhere on the board
+12V: U3.7 (V+), U4.7 (V+); also elsewhere on the board
-12V: U3.4 (V-), U4.4 (V-); also elsewhere on the board
/GPIO8: U2.1 (~CS); also elsewhere on the board
/GPIO10: U2.3 (SDI/SDO); also elsewhere on the board
/GPIO11: U2.2 (SCK); also elsewhere on the board
/GPIO20: R6.1, U1.2; also elsewhere on the board
/Voltmeter/VOLTAGE_INPUT: R1.1; also elsewhere on the board
GND: U2.4 (V_{SS}), U2.7 (P0B), U3.3 (+), U4.3 (+); also elsewhere on the board
unnamed: R3.2, R4.1, U3.6
unnamed: R5.2, U1.5 (+), U4.6
unnamed: U1.4 (-), U2.6 (P0W)
unnamed: R1.2, R2.2, R3.1, U3.2 (-)
unnamed: R4.2, R5.1, U4.2 (-)

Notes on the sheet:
Voltmeter

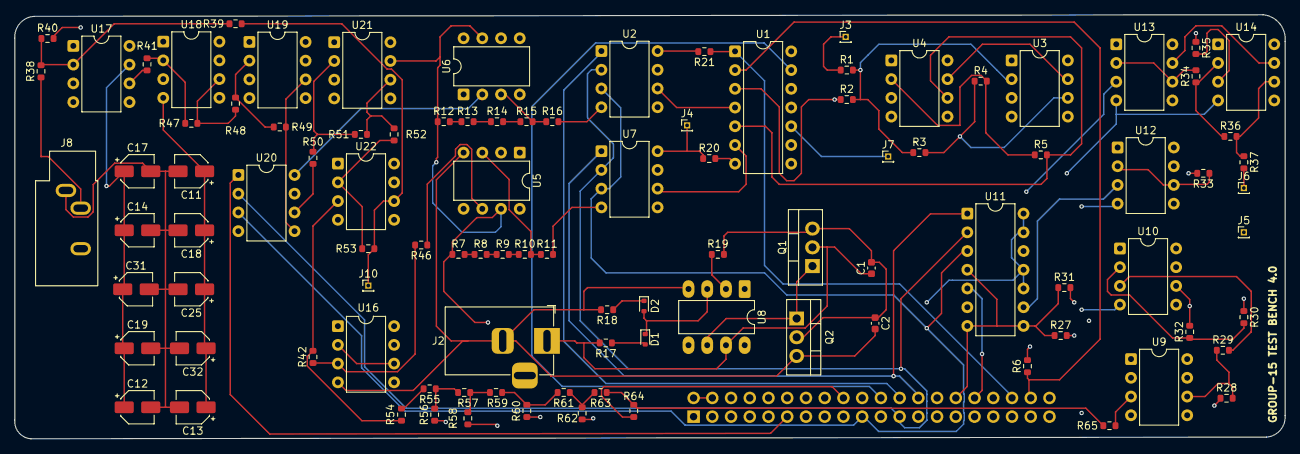
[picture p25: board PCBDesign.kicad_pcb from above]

Board: 4 copper layers, 172.3 x 57.5 mm, 103 parts (1 on the bottom side), 75 nets.

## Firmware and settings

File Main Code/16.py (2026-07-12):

"""
Testbench UI - Navigation Skeleton (Checkpoint C)
Group 15

Implements the full menu tree from the project spec:
  - Function Generator (Sine / Square)
  - Ohmmeter
  - Voltmeter (External / Internal Ref)
  - DC Reference
  - Frequency Measurement

Tolerances shown on-screen:
  Ohmmeter          +/- 10% of reading
  Voltmeter         +/- 0.2 V
  DC Reference      +/- 0.2 V
  Freq Measure      +/- 1% of reading
  Square amplitude  +/- 1 V
  Sine amplitude    +/- 0.2 V
"""

from gpiozero import RotaryEncoder, Button
from RPLCD.i2c import CharLCD
from time import sleep, time
import atexit
import os
import signal
import smbus2
import subprocess
import sys
import threading
import statistics
import RPi.GPIO as GPIO
import spidev

try:
    import pigpio
except ImportError:
    pigpio = None

# ==========================================
# 1. HARDWARE PINS & SETUP
# ==========================================
rotor = RotaryEncoder(13, 19, wrap=False, max_steps=0)
btn   = Button(26, hold_time=3)

# ---- Function Generator Hardware ----
FG_PWM_PIN  = 12
FG_SPI_BUS  = 0
FG_SPI_DEV  = 1
FG_CE0_GPIO = 8

AMP_SCALE    = 0.63
OFFSET_RATIO = 0.45

# ---- Tolerance constants (displayed to user) ----
OHM_TOL_FRACTION  = 0.10    # +/- 10% of reading
VOLT_TOL_V        = 0.2     # +/- 0.2 V on voltmeter
DC_TOL_V          = 0.2     # +/- 0.2 V on DC reference
FREQ_TOL_FRACTION = 0.01    # +/- 1% on frequency meter
SQUARE_AMP_TOL_V  = 1.0     # +/- 1 V on square-wave amplitude
SINE_AMP_TOL_V    = 0.2     # +/- 0.2 V on sine-wave amplitude

pi_fg = None
if pigpio is not None:
    try:
        _fg_candidate = pigpio.pi()
        if _fg_candidate.connected:
            pi_fg = _fg_candidate
        else:
            _fg_candidate.stop()
    except Exception:
        pi_fg = None

spi_fg = None
if pi_fg is not None:
    spi_fg = spidev.SpiDev()
    spi_fg.open(FG_SPI_BUS, FG_SPI_DEV)
    spi_fg.max_speed_hz = 1_000_000


# ---- Sine Wave Hardware (MCP4131 + audio jack) ----
SINE_CS_PIN    = 17
SINE_FREQ_MIN  = 1000
SINE_FREQ_MAX  = 10000
SINE_FREQ_STEP = 500

SINE_STEP_MIN = 1
SINE_STEP_MAX = 124

SINE_ALSA_DEVICE = "hw:2,0"
SINE_ALSA_VOLUME = 82

SINE_VOLTAGE_DATA = {
    0: 10.1, 1: 9.8, 2: 9.6, 3: 9.5, 4: 9.4, 5: 9.2,
    6: 9.1, 7: 9.0, 8: 8.9, 9: 8.8, 10: 8.6, 11: 8.5,
    12: 8.4, 13: 8.3, 14: 8.2, 15: 8.1, 16: 8.0, 17: 7.6,
    18: 7.55, 19: 7.45, 20: 7.3, 21: 7.25, 22: 7.15, 23: 7.05,
    24: 6.95, 25: 6.9, 26: 6.8, 27: 6.75, 28: 6.65, 29: 6.6,
    30: 6.45, 31: 6.4, 32: 6.35, 33: 6.25, 34: 6.15, 35: 6.0,
    36: 5.95, 37: 5.9, 38: 5.85, 39: 5.75, 40: 5.65, 41: 5.55,
    42: 5.5, 43: 5.5, 44: 5.45, 45: 5.35, 46: 5.2, 47: 5.15,
    48: 5.1, 49: 5.05, 50: 4.95, 51: 4.95, 52: 4.85, 53: 4.75,
    54: 4.7, 55: 4.7, 56: 4.6, 57: 4.55, 58: 4.5, 59: 4.4,
    60: 4.3, 61: 4.3, 62: 4.25, 63: 4.2, 64: 4.1, 65: 3.92,
    66: 3.88, 67: 3.8, 68: 3.76, 69: 3.72, 70: 3.64, 71: 3.6,
    72: 3.56, 73: 3.48, 74: 3.4, 75: 3.36, 76: 3.32, 77: 3.26,
    78: 3.2, 79: 3.16, 80: 3.08, 81: 3.04, 82: 3.0, 83: 2.91,
    84: 2.85, 85: 2.79, 86: 2.75, 87: 2.71, 88: 2.63, 89: 2.59,
    90: 2.51, 91: 2.47, 92: 2.43, 93: 2.39, 94: 2.31, 95: 2.25,
    96: 2.19, 97: 2.15, 98: 2.07, 99: 2.03, 100: 1.97, 101: 1.89,
    102: 1.85, 103: 1.79, 104: 1.73, 105: 1.67, 106: 1.62, 107: 1.56,
    108: 1.5, 109: 1.43, 110: 1.37, 111: 1.32, 112: 1.26, 113: 1.19,
    114: 1.14, 115: 1.07, 116: 1.01, 117: 0.94, 118: 0.86, 119: 0.8,
    120: 0.53, 121: 0.63, 122: 0.59, 123: 0.55, 124: 0.46,
}
_SINE_SORTED_STEPS = sorted(SINE_VOLTAGE_DATA.keys())

GPIO.setwarnings(False)
GPIO.setmode(GPIO.BCM)
GPIO.setup(SINE_CS_PIN, GPIO.OUT)
GPIO.output(SINE_CS_PIN, GPIO.HIGH)


def initialize_lcd(address=0x27, port=1, retries=3):
    try:
        bus = smbus2.SMBus(port)
        bus.read_byte(address)
        bus.close()
    except OSError:
        pass
    sleep(0.1)
    for attempt in range(retries):
        try:
            _lcd = CharLCD('PCF8574', address, port=port, cols=20, rows=4)
            _lcd.auto_linebreaks = False
            return _lcd
        except OSError as e:
            if attempt < retries - 1:
                sleep(0.5)
            else:
                raise e

lcd = initialize_lcd()
sleep(0.3)


# ---- Ohmmeter Hardware ----
OHM_CS_PIN    = 8
OHM_COMP_PIN  = 21
OHM_MAX_STEPS = 128
OHM_KNOWN_R   = 10000.0

GPIO.setwarnings(False)
GPIO.setmode(GPIO.BCM)
GPIO.setup(OHM_CS_PIN, GPIO.OUT)
GPIO.output(OHM_CS_PIN, GPIO.HIGH)
GPIO.setup(OHM_COMP_PIN, GPIO.IN)

spi_meas = spidev.SpiDev()
spi_meas.open(0, 0)
spi_meas.max_speed_hz = 1_000_000


# ---- Voltmeter Hardware ----
VOLT_COMP_PIN  = 6
VOLT_MAX_STEPS = 128

GPIO.setup(VOLT_COMP_PIN, GPIO.IN)

VOLTAGE_DATA = {
    0: -4.95, 1: -4.80, 3: -4.70, 4: -4.60, 5: -4.50, 7: -4.40, 8: -4.30, 9: -4.20,
    10: -4.10, 12: -4.00, 13: -3.90, 14: -3.80, 15: -3.70, 17: -3.60, 18: -3.50,
    19: -3.40, 20: -3.30, 22: -3.20, 23: -3.10, 25: -3.00, 26: -2.90, 27: -2.80,
    28: -2.70, 29: -2.60, 31: -2.50, 32: -2.40, 33: -2.30, 34: -2.20, 36: -2.10,
    37: -2.00, 39: -1.90, 40: -1.80, 41: -1.70, 42: -1.60, 43: -1.50, 45: -1.40,
    46: -1.30, 47: -1.20, 49: -1.10, 50: -1.00, 51: -0.90, 52: -0.80, 54: -0.70,
    55: -0.60, 56: -0.50, 57: -0.40, 58: -0.30, 60: -0.20, 61: -0.10, 62: 0.00,
    64: 0.10, 65: 0.20, 66: 0.30, 67: 0.40, 68: 0.50, 70: 0.60, 71: 0.70, 72: 0.80,
    74: 0.90, 75: 1.00, 76: 1.10, 77: 1.20, 79: 1.30, 80: 1.40, 81: 1.50, 82: 1.60,
    84: 1.70, 85: 1.80, 86: 1.90, 87: 2.00, 89: 2.10, 90: 2.20, 92: 2.30, 93: 2.40,
    94: 2.50, 95: 2.60, 96: 2.70, 98: 2.80, 99: 2.90, 100: 3.00, 101: 3.10, 103: 3.20,
    104: 3.30, 105: 3.40, 106: 3.50, 108: 3.60, 109: 3.70, 110: 3.80, 112: 3.90,
    113: 4.00, 114: 4.10, 116: 4.20, 117: 4.30, 118: 4.40, 119: 4.50, 120: 4.60,
    122: 4.70, 123: 4.80, 124: 4.90, 125: 5.00
}
_VOLT_SORTED_STEPS = sorted(VOLTAGE_DATA.keys())


# ---- DC Reference Hardware ----
DAC_PINS   = [14, 15, 18, 23, 24]
DAC_LEVELS = 32
DAC_V_MIN  = -5.00
DAC_V_MAX  =  4.80
DAC_STEP   = (DAC_V_MAX - DAC_V_MIN) / (DAC_LEVELS - 1)

for _pin in DAC_PINS:
    GPIO.setup(_pin, GPIO.OUT)
    GPIO.output(_pin, GPIO.LOW)


# ---- Frequency Meter Hardware ----
FREQ_PIN        = 25
FREQ_SAMPLE_CAP = 100

pi_freq = None
if pigpio is not None:
    try:
        _candidate = pigpio.pi()
        if _candidate.connected:
            pi_freq = _candidate
            pi_freq.set_mode(FREQ_PIN, pigpio.INPUT)
            pi_freq.set_pull_up_down(FREQ_PIN, pigpio.PUD_OFF)
        else:
            _candidate.stop()
    except Exception:
        pi_freq = None


# ==========================================
# 2. STATE VARIABLES
# ==========================================
current_freq      = 1000
current_amp_step  = 90
sine_amp_step     = 64
fg_wave_type      = "Square"
fg_output_on      = False

sine_speaker_process = None

dc_voltage   = 0.0
dc_index     = 16
dc_output_on = False

volt_source = "External"

current_resistance = None
current_voltage    = None
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

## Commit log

2026-07-12 added pcb design, schematics, code, etc.
    [Buffers.kicad_sch, Final_Power_Supply.kicad_sch, Ohmeter.kicad_sch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]
2026-07-12 added remaining filed and schematics
    [Square_Wave.kicad_sch, sin_wave_generator.kicad_sch]
2026-07-12 Remove duplicate README media and crop scope captures to waveforms.
    Drop section-level demo links and the state diagram, and tighten oscilloscope images to graticule-only views.
2026-07-12 Document SAR timing, R-2R fix, and pigpio edge capture.
    Quantify 8-bit SAR convergence time and voltmeter resolution, explain the cross-loading R-2R rationale, and describe pigpio DMA edge timestamping.
2026-07-12 Clarify power grounding, ohmmeter current limit, and audio gain.
    Document star-ground isolation, DUT series limiting for the MCP4131, and U4 gain scaling from the Pi line-level audio output.
2026-07-12 Document system sampling concurrency and subsystem integration.
    Clarify non-blocking SAR timing vs UI refresh, ohmmeter non-linear resolution bounds, and square-wave PWM RC filtering.
